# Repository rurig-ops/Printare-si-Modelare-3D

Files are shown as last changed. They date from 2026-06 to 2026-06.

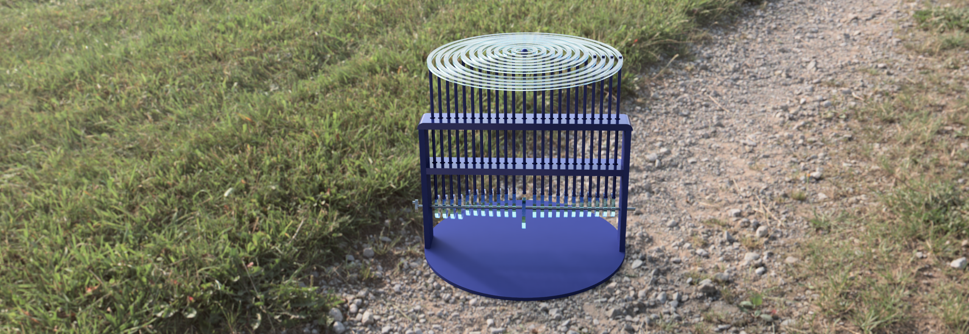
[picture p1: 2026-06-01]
montare_finala_2026-Jun-01_12-20-54PM-000_CustomizedView40636737801_png.png

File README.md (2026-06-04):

# 3D Printing and Modeling - Final Project
### 🌊 Kinetic Sculptures: Mechanical Water Droplet

This repository contains the final project for the **3D Printing and Modeling** course (2025-2026). 

🔬 [About](#-about) | 📐 [Design & Contribution](#-design--contribution) | ⚙️ [Movement & Simulation](#%EF%B8%8F-movement--simulation) | 🖨️ [Printability & Tolerances](#%EF%B8%8F-printability--tolerances) | 📎 [Components & Files](#-components--files)

---

## 🔬 About

### Course Objectives:
* Development of 3D Modeling and CAD prototyping skills inside Autodesk Fusion 360.
* Understanding parametric design principles and mechanical assemblies.
* Designing functional parts with strict printability and mechanical constraints.
* Simulating physical assemblies using constraints, motion links, and motion studies.

### Project Description:
This project is a functional, 3D-printable kinetic sculpture designed inside Fusion 360. It replicates the organic movement of a water droplet ripple or an acoustic wave using a purely mechanical assembly. By rotating a central crank handle, a sequential series of eccentric cams/disks pushes an array of vertical push-rods upward in a precise wave-like phase shift, which in turn drives a series of concentric top rings.

---

## 📐 Design & Contribution

### Inspiration Sources:
The design was inspired by DIY cardboard automation mechanisms found online:
* *3D printing a Mechanical Water droplet* (Inspired by YouTube references: XYdF-B0r_V0 & A-rVbZ-GepY)

### My Design Contribution (Redesign Process):
While inspired by cardboard mockups, translating a dynamic mechanism from cardboard (a flexible, forgiving material glued with hot glue) into a precise, rigid, digital CAD model required heavy redesigning:
1. **Structural Rigidity:** Re-engineered the open frame into a rigid, self-supporting pillar system (`baza+laterale`) with a centralized internal guide plate (`sertar_mij`) to prevent the rods from buckling or tilting.
2. **From Cardboard to Solid Bodies:** Designed custom parametric thicknesses for all concentric circles (`Cercuri_superioare`) and the drive shaft cams to withstand physical material stress.
3. **Contact Optimization:** Modified the bottom tip of the vertical push-rods into spherical/rounded profiles. Cardboard designs use flat joints which create high friction and lock up; rounded contact points ensure smooth tangential sliding over the cam surfaces.
4. **CAD Organization:** Cleaned, renamed, and modularized the Browser Tree into dedicated sub-assemblies (e.g., grouping the upper rings and vertical rods) ensuring a professional project structure.

---

## ⚙️ Movement & Simulation

The mechanism requires integrated complex motions to accurately mimic wave propagation:

* **Joints Defined:** * `Revolute Joint` on the main crank shaft (`bara_32cm` & `Maner`) to allow constant rotation.
  * `Slider Joints` on the vertical rods (`Bar_vert`) allowing them to guide smoothly up and down.
  * `Slider Joints` on the upper rings (`Cercuri_sup`) allowing them to guide smoothly up and down.
* **Tangent Relationships:** Implemented precise geometric tangent relationships between the tip of each vertical rod and its corresponding eccentric drive disc to map out the exact wave profile physically.
* **Motion Link:** Created an interconnected kinematic motion link (`Assemble -> Motion Link`) linking the crank shaft's rotary movement to the linear motion of the guide rods ($360^\circ$ rotation $\rightarrow$ specific linear stroke amplitude in mm). *Note: Due to Fusion 360's over-constraint safety protocols with combined mathematical links and non-linear geometric tangents, the link is preserved in the history tree under 'Relationships' and suppressed where needed to avoid software freeze.*
* **Motion Study:** Configured a native Motion Study timeline animation executing a continuous loop ($0^\circ \rightarrow 360^\circ \rightarrow 720^\circ$) to simulate the automated kinetic sequence without needing manual mouse dragging.

---

## 🖨️ Printability & Tolerances

Although printing is optional, the model was engineered strictly from a **Design-for-Additive-Manufacturing (DfAM)** perspective:

* **Support Minimization:** The main base plate, structural pillars, and concentric top rings are designed to be printed flat on the build plate, completely removing the need for support material on those components.
* **Chamfers and Fillets:** Added safety fillets on the large outer base profile to distribute impact stresses and eliminate sharp edges. 

---

## 📎 Components & Files

### Components Used:
1. **`baza+laterale` (Main Base Frame):** Serves as the stable foundation and holds the horizontal rotating shaft.
2. **`bara_32cm` (Crank Shaft Assembly):** Houses the array of phased eccentric disks/cams that generate the mechanical wave.
3. **`Cercuri_mici` (Mechanism small circles):** the circles that rotate with the crank and lift/lower the push-rods.
4. **`Bar_vert` (Push-Rods Array):** Translates the rotary cam action into vertical linear motion.
5. **`Cercuri_superioare` (Concentric Wave Rings):** The final visual output that represents the undulating water ripple.

### Included Project Files:
* `montare_finala.f3d` - Full parametric Autodesk Fusion 360 Project File.
* `*.stl` files - Exported print-ready meshes for each structural component.
* `*.gcode` files - Sliced files tailored with appropriate print orientations.

---

## 📐 Resources & Credits

* 📹 **Functional Demo Video:** [(https://youtu.be/YVgBpsRyGC8)]
* 📦 Inspiration Reference: Mechanical Water Droplet Automaton Concepts.

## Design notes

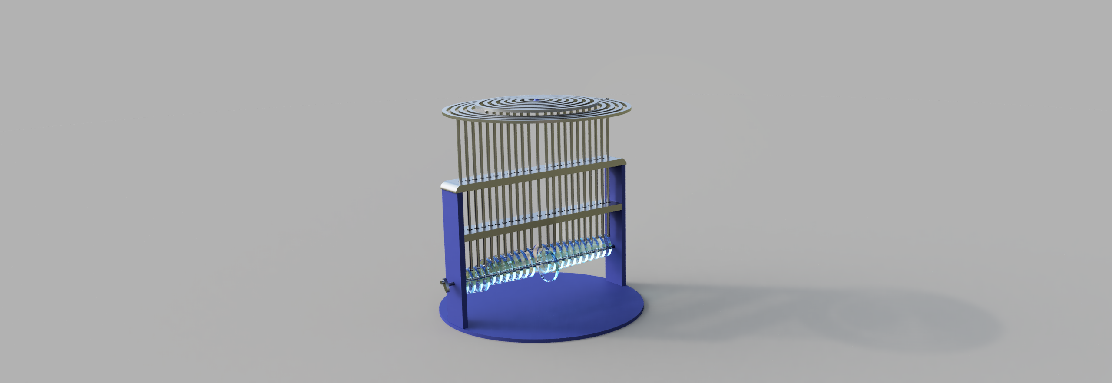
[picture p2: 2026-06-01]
montare_finala_2026-Jun-01_11-46-41AM-000_CustomizedView9707181467_png.png

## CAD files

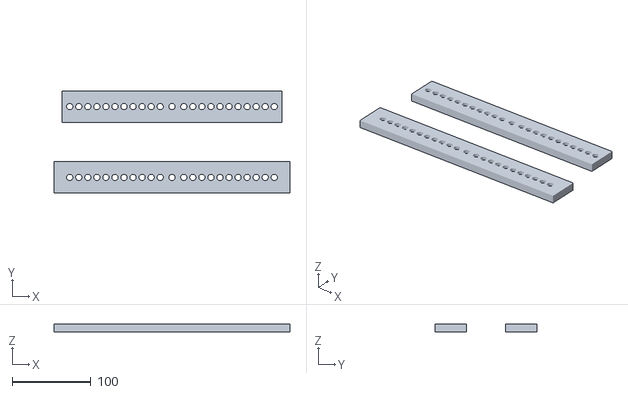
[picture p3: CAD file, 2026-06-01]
stl/Sertar+gauri.stl
300.0 x 130.0 x 10.0

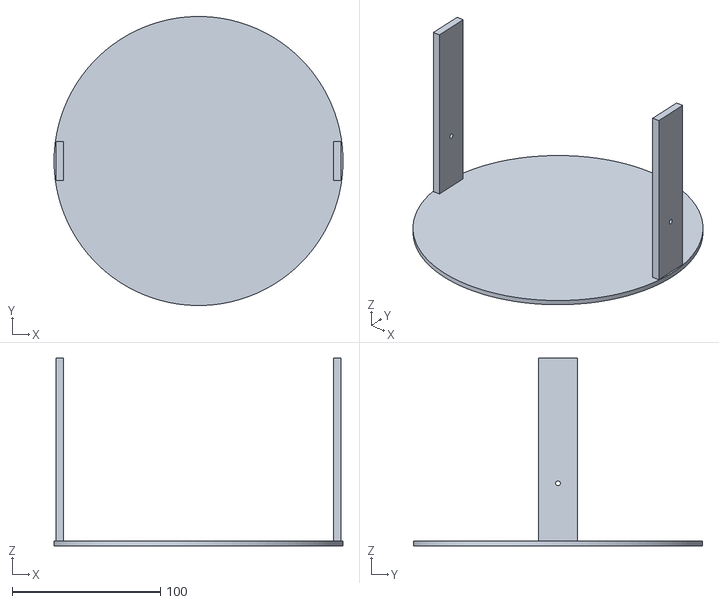
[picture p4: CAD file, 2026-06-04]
stl_sized down pt printare/baza+laterale_mic.stl
195.0 x 195.0 x 126.8

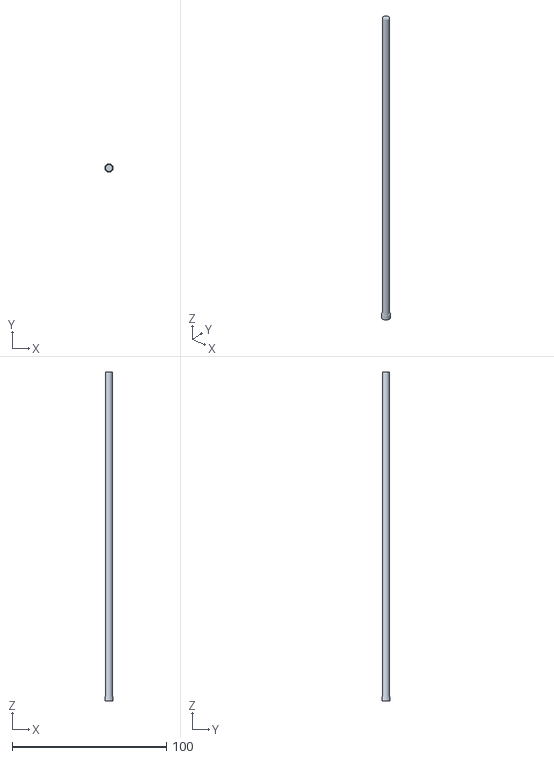
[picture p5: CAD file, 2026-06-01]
stl/bara_vert.stl
5.50 x 5.50 x 213.0

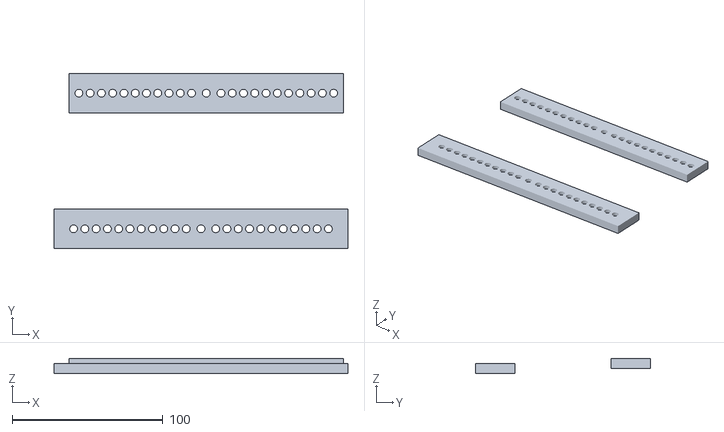
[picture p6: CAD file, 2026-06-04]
stl_sized down pt printare/Sertar+gauri_mic.stl
195.0 x 116.0 x 10.0

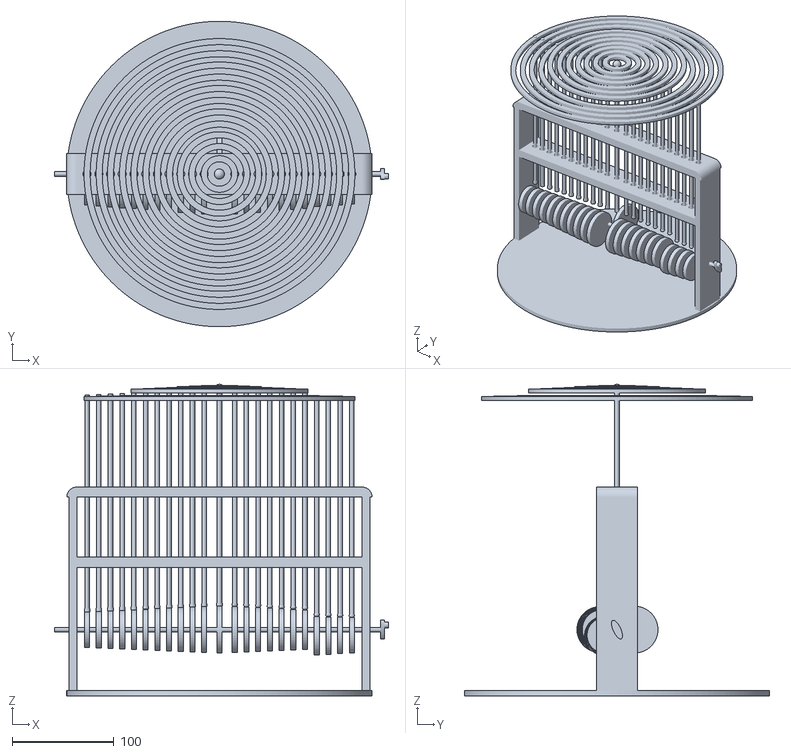
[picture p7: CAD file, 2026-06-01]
stl/montare_finala.stl
328.0 x 300.0 x 306.0

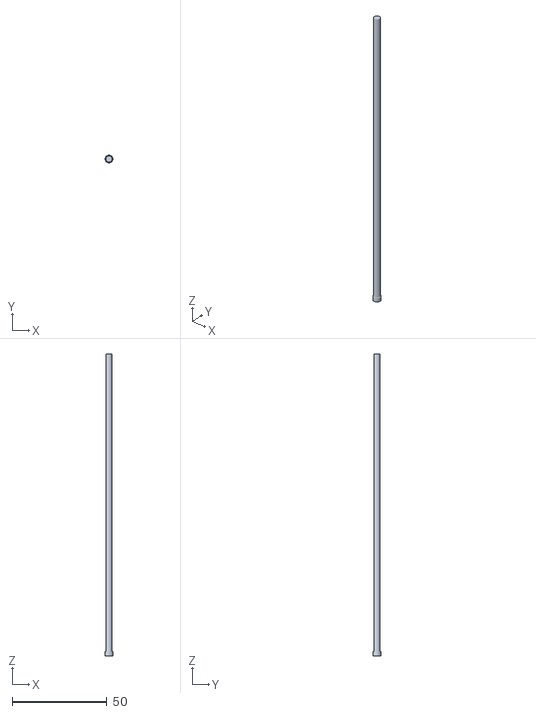
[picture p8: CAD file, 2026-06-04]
stl_sized down pt printare/bara_vert_mic.stl
4.12 x 4.12 x 159.8

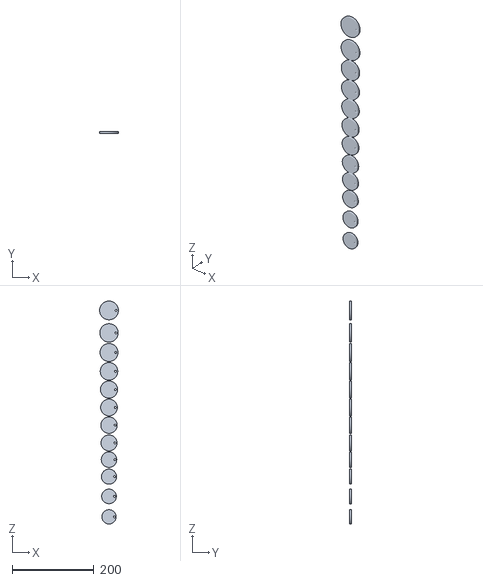
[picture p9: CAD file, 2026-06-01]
stl/cercuri_mici.stl
46.0 x 5.00 x 545.5

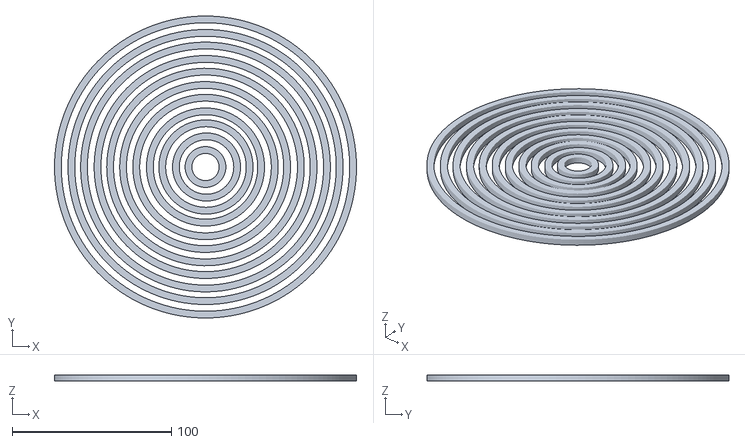
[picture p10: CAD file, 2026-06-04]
stl_sized down pt printare/cerc_sup_mic.stl
189.5 x 189.5 x 4.00

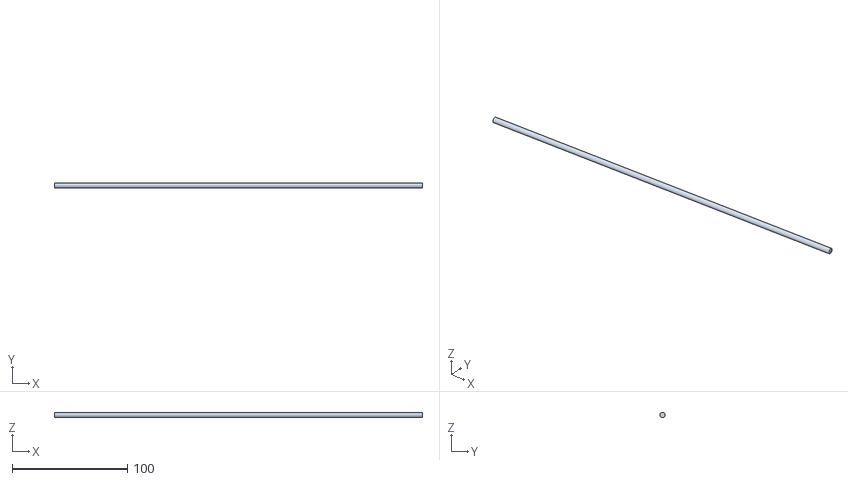
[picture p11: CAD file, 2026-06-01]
stl/bara_32cm.stl
320.0 x 4.50 x 4.50

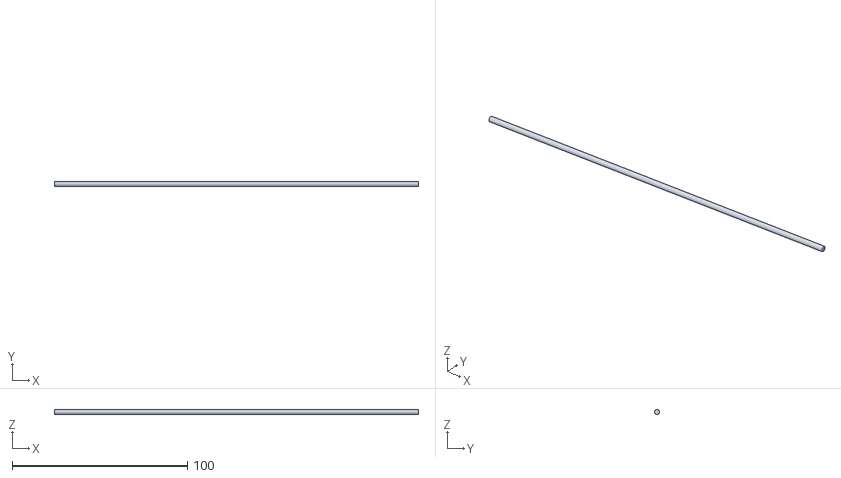
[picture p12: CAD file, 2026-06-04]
stl_sized down pt printare/bara_32cm_mic.stl
208.0 x 2.93 x 2.92

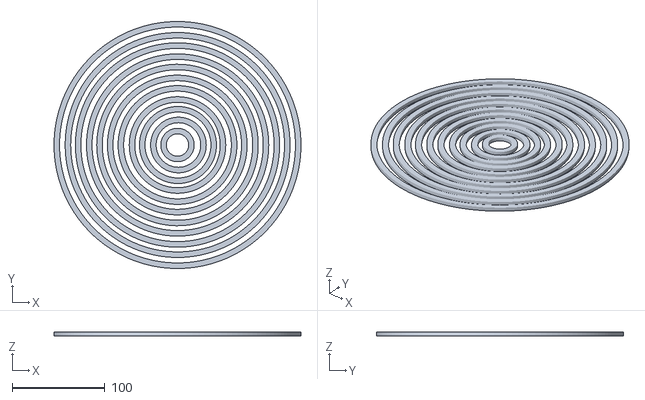
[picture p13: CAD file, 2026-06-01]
stl/cerc_sup.stl
266.0 x 265.9 x 4.00

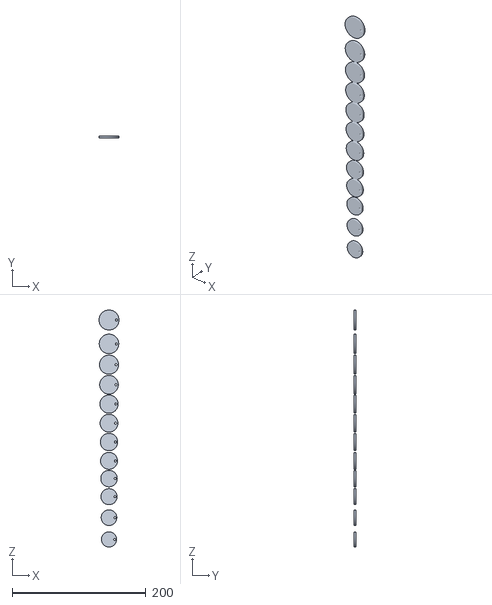
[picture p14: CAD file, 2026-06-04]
stl_sized down pt printare/cercuri_mici_mic.stl
29.9 x 3.25 x 354.6

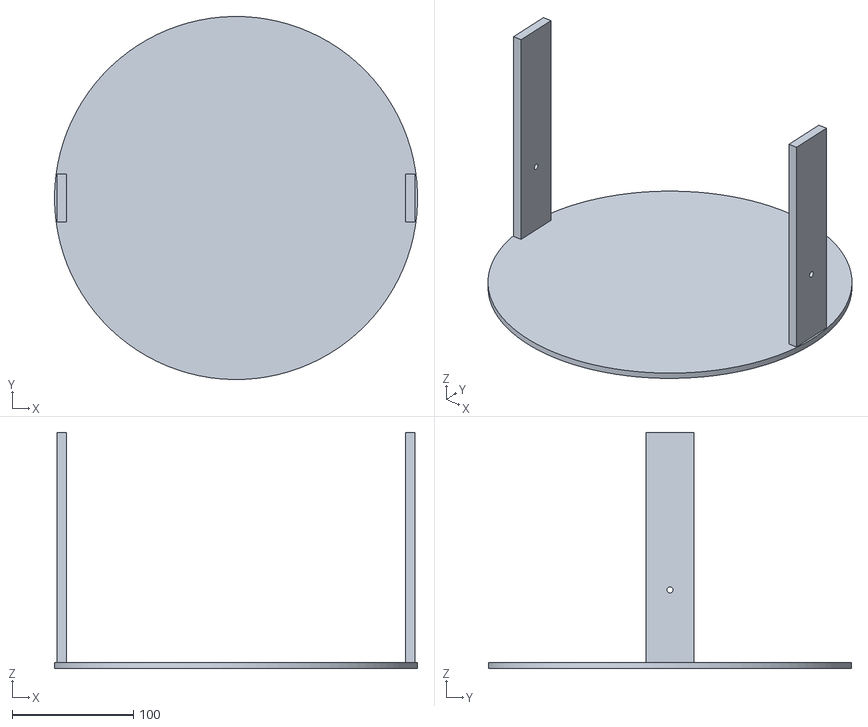
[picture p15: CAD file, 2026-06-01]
stl/baza+laterale.stl
299.9 x 300.0 x 195.0

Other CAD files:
montare_finala.f3z

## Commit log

2026-06-01 Revise README for 3D Printing and Modeling project
    Updated the README to reflect project details and structure.
2026-06-04 Mica modificare pentru usurare printare
    [Sertar+gauri_mic.stl, bara_32cm_mic.stl, bara_vert_mic.stl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]
